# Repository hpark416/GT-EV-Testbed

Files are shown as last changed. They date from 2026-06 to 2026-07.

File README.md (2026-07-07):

# GT-EV-Testbed

### Georgia Tech ME 8803 – Special Problems (EV & Grid)

A custom dual-motor electric vehicle control system built around repurposed Segway/Ninebot hoverboard motors, a FLIPSKY FT85BD dual ESC, and Arduino-based vehicle control.

This project serves as both a proof-of-concept EV platform and an educational testbed for motor control, vehicle dynamics, telemetry, battery systems, and embedded software development.

---

## Project Objectives

The goal of this project is to develop a low-cost, modular electric vehicle platform capable of:

- Differential drive control
- Zero-radius turning
- Radio control operation
- Telemetry collection
- Battery and power monitoring
- Expandable software architecture
- Future BLE/mobile dashboard integration
- Educational demonstrations and experimentation

---

## Current Hardware

### Powertrain

- 2x Segway/Ninebot hoverboard hub motors
- FLIPSKY FT85BD dual ESC
- Stock Segway 15S lithium-ion battery pack
- Emergency stop switch
- Power distribution board
- Main power breaker

### Control System

- Arduino Mega 2560
- Radiolink RC receiver
- Radiolink RC transmitter
- PPM control signal to FT85BD

### Planned Electronics

- Arduino UNO R4 WiFi
- UART telemetry interface
- Bluetooth/mobile dashboard
- Data logging
- Battery monitoring

---

## Vehicle Specifications

### Battery

| Parameter | Value |
|---|---:|
| Chemistry | Lithium-Ion |
| Configuration | 15S |
| Nominal Voltage | ~54.8V |
| Approximate Energy | ~236 Wh |

### Motors

| Parameter | Value |
|---|---:|
| Type | Hoverboard hub motor |
| Quantity | 2 |
| Sensor Type | Hall sensors |
| Pole Pairs | 7 |

### Controller

| Parameter | Value |
|---|---:|
| ESC | FLIPSKY FT85BD |
| Configuration | Dual motor |
| Current Control Method | PPM + UART telemetry (Flipsky protocol) |
| Active tuning focus | Duty-cycle mode for low-ERPM crawl |

---

## Current Software Features

- Radiolink RC input
- Interrupt-based RC pulse capture
- PPM output to FT85BD
- Differential drive
- Arcade-style steering
- Zero-radius pivot mode
- Adjustable forward speed limit
- Separately capped reverse speed
- Steering sensitivity tuning
- Input deadband filtering
- Exponential response shaping
- Ramp-rate limiting
- UART telemetry from FT85BD (`UartSpeedController`, optional ERPM drive)

---

## ESC Configuration

Current controller configuration target:

```text
Control Mode: Speed Reverse
Input Type: PPM
Pulse Range: 1000 us - 1500 us - 2000 us
Motor Startup: Hall
Hall Sensors: Enabled
Master ESC ID: 101
Slave ESC ID: 102
```

---

## Repository Structure

```text
/
├── Arduino/
│   ├── SpeedReverseController/
│   ├── CurrentReverseController/
│   ├── UartSpeedController/
│   ├── UartSpeedController_NanoESP32/   (PlatformIO, Arduino Nano ESP32)
│   ├── Diagnostics/
│   │   ├── UartTelemetry_NanoESP32/
│   │   └── UartTelemetryLogger_NanoESP32/   (SD CSV logger)
│   └── Experimental/
├── Configs/
│   ├── FT85BD_Master/
│   ├── FT85BD_Slave/
│   └── Control_Setups/
├── Docs/
│   ├── Logbook/          ← engineering log (dated photo entries)
│   ├── Wiring/
│   ├── Images/
│   ├── Notes/
│   └── TestLogs/
└── README.md
```

---

## UART Setup (FT85BD ↔ Arduino Mega)

The `Arduino/UartSpeedController/` sketch talks to the FT85BD over the VESC UART protocol at **115200 baud**. It polls telemetry from master ESC **101** (direct UART) and slave ESC **102** (CAN forward through the master).

### 1. Hardware wiring

Use **Arduino Mega Serial1** so USB `Serial` remains free for debug output:

```text
Arduino Mega TX1 (D18)  ->  FT85BD COMM RX
Arduino Mega RX1 (D19)  ->  FT85BD COMM TX
Arduino GND             ->  FT85BD COMM GND
```

Important:

- **Common ground** is required between the Mega and FT85BD.
- FT85BD UART is **3.3 V logic**. The Mega TX line is 5 V — use a **bidirectional level shifter** (recommended) or a resistor divider on the Mega TX → FT85BD RX path. Connect Mega RX to FT85BD TX through the level shifter as well.
- Do **not** connect the Mega to a powered ESC UART port until wiring is verified with a multimeter.
- Keep the **e-stop** and main breaker accessible during all UART bring-up tests.

See `Docs/Wiring/README.md` for the full pin map including PPM and RC wiring.

### 2. FT85BD / VESC Tool configuration

1. Connect the FT85BD to a PC via USB and open **VESC Tool** (or the FLIPSKY configuration app).
2. Confirm controller IDs:
   - Master (left): **101**
   - Slave (right): **102**
3. Under **App Settings → General**, set the app to **UART** (or UART + another input only if you understand the priority rules). For UART-only testing, disconnect PPM control wires to avoid conflicting inputs.
4. Under **App Settings → UART**, confirm baud rate **115200** (default).
5. Under motor settings, confirm **Speed** control mode matches your intent (Speed Reverse for this sketch).
6. Load and write the known-good XML configs from `Configs/FT85BD_Master/`, `Configs/FT85BD_Slave/`, and `Configs/Control_Setups/` as needed.
7. Power-cycle the ESC after writing configuration.

### 3. Upload firmware

**Arduino Mega (Arduino IDE):** open `Arduino/UartSpeedController/UartSpeedController.ino`.

**Arduino Nano ESP32 (PlatformIO):** open `Arduino/UartSpeedController_NanoESP32/` and run `pio run -t upload` (see that folder's `README.md`). Uses D8/D9 for FT85BD UART; 3.3 V logic — no level shifter needed.

For either board:

1. Leave `ENABLE_UART_RPM_CONTROL` set to **`false`** for the first test (telemetry only).
2. Upload the sketch.

### 4. Verify telemetry

1. Open the Serial Monitor at **115200 baud**.
2. With the ESC powered (wheels off the ground), you should see:
   - `FW version: x.xx` after startup (if the master responds)
   - Periodic lines: `ERPM`, `V` (input voltage), `I` (motor current), `Fault`, `ID`
3. Spin a motor by hand or apply a light command — ERPM and current should change.
4. Confirm both IDs **101** and **102** appear as telemetry alternates between master and slave.

If there is no response:

- Swap TX/RX if needed (they must cross).
- Recheck ground and level shifting.
- Confirm only one device drives the UART lines.
- Verify baud rate and that the UART app is enabled on the ESC.

### 5. Enable RC + ERPM control (optional)

Only after telemetry is stable:

1. Set `ENABLE_UART_RPM_CONTROL` to **`true`** and re-upload.
2. Confirm RC receiver wiring (CH2 → D2, CH4 → D3) matches `SpeedReverseController`.
3. Test with wheels **off the ground** and low ERPM limits (`MAX_FORWARD_ERPM`, `MAX_REVERSE_ERPM` in the sketch).
4. Tune `INVERT_MASTER` / `INVERT_SLAVE` so both wheels turn in the expected direction.
5. Verify RC failsafe: releasing signal should command **0 ERPM** on both motors.

### 6. Coexistence with PPM control

`SpeedReverseController` (PPM on D9/D10) and `UartSpeedController` (Serial1) can share the same RC input pins but should **not** drive the ESC simultaneously. Use one control method at a time:

| Mode | ESC input | Arduino sketch |
|---|---|---|
| PPM drive | PPM pins | `SpeedReverseController` |
| UART telemetry / drive | COMM UART | `UartSpeedController` |

---

## Progress Notes

### 2026-06 — UART bring-up (Nano ESP32)

- Verified FT85BD speaks **Flipsky UART** (`AA … DD`), not VESC packets.
- Dual-UART wiring (Serial1 → master 101, Serial2 → slave 102) confirmed for telemetry.
- Diagnostics: `UartTelemetry_NanoESP32` for serial bring-up.

### 2026-07-07 — Control mode evaluation (duty cycle vs speed vs current)

Evaluated FT85BD control modes for differential drive with a human rider on the cart:

| Mode | Result |
|---|---|
| **Current** | Strong torque at low speed, but **too unstable** for differential drive — especially with a rider. Not suitable as the primary cart mode. |
| **Speed** | Good **differential stability**, but at low ERPM (~400 range) motors often **stuck, buzzed, and hummed** — poor crawl behavior. |
| **Duty cycle** | **Smooth motion at low ERPM** (~400 range) without the speed-mode lock-up/buzz. Current working direction for low-speed tuning. |

Added `Arduino/Diagnostics/UartTelemetryLogger_NanoESP32/` — Nano ESP32 + **Adafruit microSD SPI breakout** logs dual-UART telemetry (voltage, RPM, duty, current, temps) to CSV for post-run analysis while testing control modes.

### 2026-07-07 — Engineering logbook from photo narration

- Created **`Docs/Logbook/`** — dated entries for **100+ images** in `Docs/Images/`, transcribed from narration video `Docs/Notes/2026-07-07 16-58-03.mp4` (video gitignored).
- See [`Docs/Logbook/INDEX.md`](Docs/Logbook/INDEX.md) for session index (2026-05-22 through 2026-07-07).

---

## TODO

- [ ] **Steering tuning at low RPM** — `SPEED_STEERING_GAIN` in `UartSpeedController_NanoESP32` is too weak at lower speeds; increase low-RPM steering authority without destabilizing the cart.
- [ ] Correlate SD log CSV data with duty-cycle settings in Flipsky ESC Tool (document optimal duty range around ~400 ERPM).
- [ ] Compare logged duty/RPM/current traces across speed vs duty modes for the same RC input profile.
- [ ] Update FT85BD XML configs in `Configs/` when duty-cycle setup is finalized.
- [ ] Closed-loop wheel sync / telemetry dashboard (BLE or post-processing pipeline from SD logs).

---

## Development Status

### Completed

- Battery integration
- FT85BD bring-up
- Hall sensor motor identification
- RC receiver integration
- Arduino PPM controller
- Differential drive control
- Pivot steering mode
- Initial ESC configuration workflow
- UART telemetry sketch (`UartTelemetry_NanoESP32`, Flipsky protocol)
- Nano ESP32 dual-UART speed controller (`UartSpeedController_NanoESP32`)
- UART telemetry SD logger (`UartTelemetryLogger_NanoESP32`)

### In Progress

- **Duty-cycle control** tuning for smooth low-ERPM crawl (~400 ERPM)
- **Steering gain** at low RPM (`UartSpeedController_NanoESP32`)
- Low-speed control tuning and SD log analysis
- Differential steering refinement
- Configuration management for master/slave ESC settings

### Planned

- ESC config snapshots for duty-cycle mode in `Configs/`
- BLE / mobile telemetry dashboard
- Automated log analysis scripts for SD CSV files
- Closed-loop wheel speed matching

---

## Lessons Learned

- Hoverboard motors are capable low-cost EV drive units.
- Hall sensor startup significantly improves low-speed performance.
- **Current mode** gives torque at crawl speeds but is **unstable for differential drive with a rider** — not viable as the primary cart mode.
- **Speed mode** gives good differential stability but can **buzz/hum and hang at low ERPM** (~400 range).
- **Duty-cycle mode** currently provides the **smoothest low-ERPM motion** on this platform; use SD logging to tune further.
- Flipsky UART (`AA … DD`) is required for FT85BD — not VESC packets.
- PPM remains a proven fallback; UART dual-port telemetry + SD logging supports mode comparison.
- Master/slave ESC IDs and XML configuration files must be carefully version-controlled.

---

## Author

Hyungjun Park  
Georgia Institute of Technology  
ME 8803 – Special Problems (EV & Grid)

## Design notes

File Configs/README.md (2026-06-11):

# FT85BD Configuration Files

This folder stores **FLIPSKY FT85BD XML motor and control setup files** exported from the VESC Tool–compatible configuration workflow.

## Layout

| Folder | Contents |
|---|---|
| `FT85BD_Master/` | Master (left) motor setup XML |
| `FT85BD_Slave/` | Slave (right) motor setup XML |
| `Control_Setups/` | Shared control/input setup XML (PPM mode, calibration, ramp, reverse timing) |

The FT85BD dual ESC uses separate master/slave identities. Do not overwrite one side with the other.

## Controller IDs

Each ESC must have a **unique CAN/controller ID**. Do not duplicate IDs across master and slave.

| ESC | ID |
|-----|----|
| Master | **101** |
| Slave | **102** |

Always verify the connected ESC ID before writing setup.

## Suggested naming convention

```text
Master_MotorSetup_YYYYMMDD.xml
Slave_MotorSetup_YYYYMMDD.xml
Master_ControlSetup_YYYYMMDD.xml
Slave_ControlSetup_YYYYMMDD.xml
```

## File types

- **Motor setup** — motor identification values, current limits, power limits, ERPM limits, and battery settings.
- **Control setup** — input type, PPM mode, PPM calibration, deadband, ramp times, reverse timing, and ESC ID.

## Usage

1. Identify motors and complete hall-sensor detection on each ESC individually.
2. Export XML from the configured unit into the appropriate folder here.
3. Always save the working configuration before experimenting.
4. Commit configs when they represent a known-good, tested setup.
5. Document significant changes in `Docs/Notes/` and `Docs/TestLogs/`.

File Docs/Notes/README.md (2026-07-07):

# Development Notes

Informal scratch notes and **local-only media** (videos are gitignored).

## Engineering logbook

Structured, dated entries with photos are in **[`../Logbook/`](../Logbook/)** — start at [`../Logbook/README.md`](../Logbook/README.md) and [`../Logbook/INDEX.md`](../Logbook/INDEX.md).

Narration source video (local, not in git): `2026-07-07 16-58-03.mp4` in this folder.

## Suggested files

```text
motor_identification.md
battery_observations.md
control_mode_comparison.md
low_speed_tuning.md
speed_reverse_tuning.md
uart_notes.md
```

---

## Test Logs

See also `Docs/TestLogs/` for structured bench and cart test records.

| Date | Sketch / Config | Summary | Result |
|---|---|---|---|
| | | | |

---

## Tuning Notes

- Speed reverse tuning:
- Current reverse tuning:
- Pivot mode parameters:
- RC expo / scaling:

---

## Motor Identification Results

| Motor | Pole Pairs | R (mΩ) | L (µH) | Direction | Notes |
|---|---|---|---|---|---|
| Master (left) | | | | | |
| Slave (right) | | | | | |

---

## Battery Observations

- Resting voltage:
- Under-load behavior:
- Charging / storage notes:

---

## Control Mode Comparisons

| Aspect | Speed Reverse | Current Reverse |
|---|---|---|
| Low-speed feel | | |
| Wheel sync | | |
| Steering response | | |
| Heat / efficiency | | |
| Overall preference | | |

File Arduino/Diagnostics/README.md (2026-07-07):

# Diagnostics

This folder contains sketches used to isolate and verify hardware behavior.

Recommended diagnostic order:

1. RC input pulse reader
2. PPM pass-through
3. Identical PPM output to both ESCs
4. Fixed pulse step test
5. One-motor ESC test
6. UART telemetry test — `UartTelemetry_NanoESP32/` (Nano ESP32, read-only — run this first)
7. UART telemetry SD logger — `UartTelemetryLogger_NanoESP32/` (dual UART + Adafruit microSD CSV log)
8. Full UART controller — `../UartSpeedController_NanoESP32/` (Flipsky protocol, dual UART, drive)

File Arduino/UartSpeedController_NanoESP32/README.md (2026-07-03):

# UartSpeedController — Arduino Nano ESP32 (PlatformIO)

UART speed controller for the **FLIPSKY FT85BD** on the **GT-EV meka cart**, using the **Flipsky FT ESC UART protocol** (`AA … DD`). Replaces PPM with signed **current** commands (cmd 4) over dual COMM ports.

**Firmware version:** `1.1.0` (printed at boot on USB serial).

**Not** VESC packets — uses `../UartSpeedController/FlipskyUart.h`.

## What this program does

The Nano ESP32 sits between the RC receiver and two FT85BD halves (master **101**, slave **102**):

1. **Reads RC PWM** on D2 (throttle) and D3 (steering) via `pulseInLong` polling (reliable on ESP32-S3).
2. **Mixes steering** for a two-motor cart: at speed, slows the inside wheel only (does not boost the outside wheel — reduces spin-out).
3. **Sends UART cmd 4** (`SET_CURRENT`) with signed target current to each ESC every control loop (ESC mode: **Current Bidirectional**).
4. **Brakes at neutral** — when both sticks are centered, commands `0` A to both wheels.
5. **Polls telemetry** (voltage, RPM, current, fault) once per second on USB serial.
6. **Sends keepalive** (cmd 25) once per second to each ESC.

### Drive behavior (current firmware)

| Stick | Behavior |
|---|---|
| Forward | Both wheels drive forward (subject to steering mix) |
| Back | Both wheels reverse (capped lower than forward) |
| Neutral (throttle + steering centered) | **Brake** — `setCurrent(0)` on both ESCs |
| Steering while moving | Inside wheel slows; outside wheel keeps throttle |
| Steering at zero throttle | **No pivot** by default (`ENABLE_PIVOT_STEERING = false`) — pivot was disabled because it caused flip risk on the cart |
| RC signal lost | Immediate stop (`0` A) |

### Why UART instead of PPM

- Finer control (signed current commands, not ~400 µs PPM range).
- No minimum-drive “breakaway kick” that made low-speed PPM choppy.
- Software ramps and expo shape low-speed response smoothly.
- Neutral can command active zero-speed hold instead of ESC center-coast.

## Bring-up summary (from diagnostics)

| Topic | Setting |
|---|---|
| Protocol | Flipsky UART (`AA` + len + payload + CRC16 + `DD`) |
| Baud | **115200** per half, written in Flipsky ESC Tool, power-cycle |
| Input type | **UART** (not PPM) on each ESC half |
| IDs | Master **101**, slave **102** |
| Preferred wiring | **Dual UART** — separate COMM harness per half (verified) |
| Logic level | Nano ESP32 **3.3 V** — direct UART to FT85BD typical |

## Wiring (dual UART — default)

Cross TX/RX on each harness. One common GND.

| Nano ESP32 | Master COMM (101) | Slave COMM (102) |
|---|---|---|
| D9 (TX) | → RX | — |
| D8 (RX) | ← TX | — |
| D5 (TX) | — | → RX |
| D4 (RX) | — | ← TX |
| D2 | RC throttle (CH2) | |
| D3 | RC steering (CH4) | |
| GND | GND | GND |

### Single-harness mode (`CAN_FORWARD_VIA_MASTER`)

Only D8/D9 to master COMM. Telemetry alternates local master + slave via cmd **16**. RPM control on slave uses CAN-forwarded cmd **39** — **dual UART is recommended for drive**.

## Flipsky ESC Tool — Control Setup

Configure **each ESC separately** (connect to master, set ID **101**, write; then slave, ID **102**, write). Battery on. Power-cycle after writing.

### Required settings

| Setting | Master (101) | Slave (102) | Notes |
|---|---|---|---|
| **Input Signal Type** | UART | UART | Must match firmware |
| **Control Mode** | **Current Bidirectional** | **Current Bidirectional** | Firmware sends cmd **4** (`SET_CURRENT`), not cmd 39 |
| **ESC ID** | **101** | **102** | Must match harness / firmware |
| **Baud rate** | 115200 | 115200 | Set on connection screen |

**Do not use** `Current Gear Reverse Brake` or other gear/throttle modes for this project — those expect pedal-like input patterns. This firmware already sends explicit RPM targets.

### Recommended settings (stability)

| Setting | Suggested | Why |
|---|---|-----|
| **Throttle Response Level** | level 1 or 2 | Gentler ESC response; firmware already ramps |
| **Signal Ramp Time Pos / Neg** | 0.20 – 0.30 s | Light ESC-side smoothing; avoid stacking with very slow ramps |
| **Reverse Delay Time** | **0** (or minimal) | Firmware handles forward/reverse instantly |
| **Assisted Turnaround Mode** | **None** | Firmware handles steering; pivot disabled for flip safety |
| **Brake-Parking Mode** | OFF to start | Try ON only if neutral still coasts after `setSpeed(0)` |
| **Slow-Release Motor** | **OFF** | Prevents creeping/coasting at zero command |
| **Minimal Current at Zero Pedal** | defaults / low | Avoid holding motor current when command is zero |
| **Multi-ESC Sync Control** | **OFF** | Each half has its own UART; Nano mixes left/right |
| **Traction Control System** | OFF to start | Optional later — see tuning guide |

### Assisted Turnaround ESC ID Setup

Leave at defaults or ignore — not used. This cart uses **two** ESCs (101/102) on separate UART ports, not the four-corner assisted-turnaround layout.

### Motor direction (both ESCs)

Set rotation direction in **Flipsky ESC Tool → Motor Setup** on each half so that **positive RPM drives the wheel forward** on the cart. Keep `INVERT_MASTER` and `INVERT_SLAVE` **false** in firmware — then straight throttle shows matching signs, e.g. `MasterRPM:22000 SlaveRPM:22000`.

Only use firmware inversion if you cannot change direction in the tool.

### After writing settings

1. **Motor Setup** — invert motor direction on whichever half spins backward when given positive RPM (wheels-up test).
2. Power-cycle both ESCs.
3. Re-flash this firmware if needed.
4. Boot serial should show RC PWM probe + harness check with correct IDs and voltage.

## Prerequisites

- [PlatformIO](https://platformio.org/) (VS Code / Cursor extension or CLI)
- Flipsky ESC Tool V1.6 (or compatible)
- RC receiver outputting **PWM** (not PPM/SBUS) on the wired channels

## Build and upload

```powershell
cd Arduino/UartSpeedController_NanoESP32
pio run -t upload
pio device monitor
```

Windows if `pio` not on PATH:

```powershell
& "$env:USERPROFILE\.platformio\penv\Scripts\pio.exe" run -t upload
& "$env:USERPROFILE\.platformio\penv\Scripts\pio.exe" device monitor
```

Monitor at **115200** baud. Boot prints firmware version first:

```text
Firmware v1.1.0
=== GT-EV-Testbed UartSpeedController (Nano ESP32) ===
Drive: UART cmd 4 SET_CURRENT (ESC: Current Bidirectional)
```

Telemetry prints once per second:

```text
RC  Thr:1520us OK  Str:1500us OK  pwm Thr:412 Str:411
[Master 101]  Vbat:56.57V  RPM:0  I:0.00A  Fault:0  ID:101
[Slave 102]  Vbat:56.67V  RPM:0  I:0.00A  Fault:0  ID:102
Cmd Master:12.5A Slave:12.5A
```

## Firmware configuration (`src/main.cpp`)

### Feature flags

| Constant | Default | Purpose |
|---|---|---|
| `ENABLE_UART_RPM_CONTROL` | `true` | `false` = telemetry only; `true` = RC drives motors |
| `READ_MODE` | `DUAL_UART_PORTS` | Dual COMM vs single UART + CAN forward |

### Speed / current limits

| Constant | Default | Purpose |
|---|---|---|
| `MAX_FORWARD_CURRENT_A` | `40.0` | Forward current cap (amps) |
| `MAX_REVERSE_CURRENT_A` | `15.0` | Reverse current cap (amps) |

### Direction / inversion

| Constant | Default | Purpose |
|---|---|---|
| `INVERT_THROTTLE` | `false` | `true` if forward stick commands reverse |
| `INVERT_STEERING` | `false` | Flip if steering is mirrored |
| `INVERT_MASTER` | `false` | Last resort — prefer motor direction in ESC Tool |
| `INVERT_SLAVE` | `false` | Last resort — prefer motor direction in ESC Tool |

### Throttle feel

| Constant | Default | Purpose |
|---|---|---|
| `THROTTLE_EXPO` | `0.60` | Higher = softer low speed (0.45 aggressive, 0.70 very gentle) |
| `THROTTLE_RAMP_STEP` | `0.015` | Accel smoothing per loop (~5 ms) |
| `THROTTLE_BRAKE_RAMP_STEP` | `0.06` | Faster decel when backing off throttle |
| `RC_DEADBAND_US` | `60` | Stick center deadband (µs) |
| `CMD_ZERO_THRESHOLD` | `0.03` | Normalized threshold for neutral brake |

### Steering / stability

| Constant | Default | Purpose |
|---|---|---|
| `SPEED_STEERING_GAIN` | `0.30` | Turn strength at speed (lower = less spin risk) |
| `MAX_TURN_REDUCTION` | `0.75` | Max inside-wheel slowdown (fraction of throttle) |
| `STEERING_EXPO` | `0.50` | Steering curve shaping |
| `STEERING_RAMP_STEP` | `0.020` | Steering input smoothing |
| `ENABLE_PIVOT_STEERING` | `false` | In-place pivot when throttle near zero — **flip risk** |
| `PIVOT_STEERING_GAIN` | `0.18` | Only if pivot enabled — keep low |

### Timing / telemetry

| Constant | Default | Purpose |
|---|---|---|
| `TELEMETRY_INTERVAL_MS` | `1000` | USB serial report rate |
| `ALIVE_INTERVAL_MS` | `1000` | ESC keepalive (cmd 25) |
| `SIGNAL_TIMEOUT_MS` | `100` | RC lost → stop if no PWM update |

## Tuning guide

### Test order

1. **ESC Tool** — UART, Current Bidirectional, IDs 101/102, power-cycle.
2. **Telemetry only** — `ENABLE_UART_RPM_CONTROL = false`, confirm voltage + IDs on boot.
3. **Wheels up** — enable RPM control, verify forward / reverse / neutral brake.
4. **Wheels down, low limits** — keep `MAX_FORWARD_RPM` at 22000 or lower.
5. **Increase speed** — bump forward cap in steps (e.g. 22000 → 28000 → 35000) only when stable.

### If forward / reverse is wrong

- Stick reversed → toggle `INVERT_THROTTLE`.
- One wheel wrong direction → fix in **ESC Tool Motor Setup** first; only then toggle `INVERT_MASTER` / `INVERT_SLAVE`.

### If low speed is still jerky

- Raise `THROTTLE_EXPO` (try 0.65 – 0.70).
- Lower `THROTTLE_RAMP_STEP` (try 0.010).
- In ESC Tool, lower **Throttle Response Level** or reduce **Signal Ramp** slightly.
- Confirm **Slow-Release Motor** is OFF.

### If it spins out or feels tippy

- Lower `SPEED_STEERING_GAIN` (try 0.20 – 0.25).
- Lower `MAX_FORWARD_RPM`.
- Keep `ENABLE_PIVOT_STEERING = false`.
- Optionally enable **Traction Control** in ESC Tool with conservative `TC Erpm Diff` values.

### If neutral coasts instead of braking

- Firmware already sends `setSpeed(0)` — confirm sticks are truly centered (watch `RC` line in serial).
- In ESC Tool try **Brake-Parking Mode ON**.
- Increase **Brake Light Level** / brake current if the tool exposes it on your firmware version.

### If RC shows STALE / never

- Receiver must output **PWM** (~1000–2000 µs, ~50 Hz), not PPM/SBUS.
- Common GND between Nano and receiver.
- Boot **RC PWM probe** should show `10/10 PWM frames` per channel — move sticks during boot.
- Try swapping a signal wire to confirm receiver channel mapping (CH2 throttle, CH4 steering).

## Bring-up order

1. Flash and run `../Diagnostics/UartTelemetry_NanoESP32/` first — confirm voltage + IDs.
2. Configure both ESCs in Flipsky ESC Tool (see above).
3. Flash this project with `ENABLE_UART_RPM_CONTROL = false` — boot harness check should match.
4. Wheels off ground → `ENABLE_UART_RPM_CONTROL = true` → test direction and neutral brake.
5. Low-speed ground test → tune per guide → raise RPM caps gradually.

## Troubleshooting

| Issue | Fix |
|---|-----|
| `Unknown board ID 'arduino_nano_esp32'` | Use espressif32 `develop` platform — see `platformio.ini` |
| `NO REPLY` on harness check | Swap RX/TX for that port; battery on; UART input in tool |
| Wrong ID on harness | Master/slave harness swapped; fix ESC ID in tool |
| No motor response with RPM enabled | Input Signal Type = UART; Control Mode = Current Bidirectional |
| Motor runs wrong direction | `INVERT_THROTTLE` / `INVERT_MASTER` / `INVERT_SLAVE` |
| RC STALE / never | PWM wiring, GND, channel mapping — see tuning guide |
| Stale VESC-based build | Rebuild — this project uses `FlipskyUart.h` only |

## Protocol reference

| Command | ID | Use |
|---|-----|-----|
| Obtain data | 0 | Telemetry (voltage, RPM, current) |
| CAN forward | 16 | Poll slave on single UART |
| FW version | 17 | Boot probe |
| Keepalive | 25 | Sent every 1 s |
| Set speed | 39 | Not used by this firmware (use cmd 4) |
| Set current | 4 | Signed target current (RC drive) |

See `../../ESCtool/Flipsky ESC Tool/.../ftesc_v1.4_1.5_1.6_uart_handle.c` and `../Diagnostics/UartTelemetry_NanoESP32/README.md` for details.

## Development notes

| Date / phase | Work |
|---|---|
| v1.0.x | Dual UART telemetry + cmd 39 RPM drive |
| v1.2.0 | PPM drive on D6/D10 (proven path); optional UART cmd 32 gear+current |
| v1.1.0 | cmd 4 SET_CURRENT for Current Bidirectional ESC mode; firmware version in boot log |
| Initial | Dual UART telemetry + RPM control from `UartTelemetry_NanoESP32` bring-up |
| Telemetry | 1 Hz USB report; RC throttle/steering in each line |
| RC input | ESP32-S3: switched from ISR to `pulseInLong` polling; boot PWM probe |
| Drive tuning | Meka cart profile: brake-at-neutral, slow-inside steering, pivot off, lower RPM caps, throttle expo/ramps |

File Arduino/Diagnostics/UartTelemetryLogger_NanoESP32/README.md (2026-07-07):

# UART Telemetry SD Logger — Arduino Nano ESP32

Records **read-only** FT85BD telemetry from both ESC halves to a **CSV file** on an **Adafruit microSD SPI breakout**. Intended for bench and cart test sessions while comparing ESC control modes (duty cycle, speed, current).

Based on the dual-UART layout from `UartTelemetry_NanoESP32` and `UartSpeedController_NanoESP32`. Sends **no** motor commands.

## Why this exists

Use this logger to capture voltage, RPM, duty cycle, current, and temperature while evaluating low-speed drive behavior — especially after switching to **duty-cycle control** (~400 ERPM) where speed mode tended to buzz/hum and current mode was unstable for differential drive with a rider.

## Wiring

### FT85BD UART (dual — same as speed controller)

| Nano ESP32 | Master COMM (101) | Slave COMM (102) |
|---|---|---|
| D9 (TX) | → RX | — |
| D8 (RX) | ← TX | — |
| D5 (TX) | — | → RX |
| D4 (RX) | — | ← TX |
| GND | GND | GND |

### Adafruit microSD SPI breakout

| Breakout | Nano ESP32 |
|---|---|
| 3V3 | 3V3 |
| GND | GND |
| CLK | D13 (SCK) |
| DO (MISO) | D12 |
| DI (MOSI) | D11 |
| CS | D7 |

Use a **FAT32** microSD card (≤32 GB recommended). Format on a PC if the card is blank.

## ESC prerequisites

1. Flipsky ESC Tool: **UART** input @ **115200** on each half (written to flash, power-cycle).
2. Master ID **101**, slave ID **102**.
3. Battery on for COMM replies.

## Build and upload

```bash
cd Arduino/Diagnostics/UartTelemetryLogger_NanoESP32
pio run -t upload
pio device monitor
```

## Output

Each boot creates the next free file: `/tel_001.csv`, `/tel_002.csv`, …

CSV columns:

```text
millis_ms,esc_id,vbat_v,rpm,motor_a,input_a,duty,fet_c,motor_c,fault
```

Header comment lines (`#`) record session metadata. Files flush every 32 rows and every 3 s.

Serial monitor prints a short live view plus `rows=` / RX byte counts every 5 s.

## Typical workflow

1. Confirm basic UART with `../UartTelemetry_NanoESP32/`.
2. Set ESC control mode in Flipsky tool (e.g. duty cycle).
3. Flash this logger, run the test maneuver, power off.
4. Remove SD card and analyze CSV in Excel / Python / `Docs/TestLogs/`.

## Troubleshooting

| Symptom | Check |
|---|---|
| `SD init FAILED` | CS=D7, SPI wiring, FAT32 card, 3V3 to breakout |
| No UART rows | Same as `UartTelemetry_NanoESP32` — battery, TX/RX swap |
| `duty` always 0 | ESC may not report duty in telemetry for all modes; RPM/current still valid |
| Empty file after run | Wait for flush (power off after status line) or call longer test |

## Related

- `../UartTelemetry_NanoESP32/` — serial-only bring-up
- `../../UartSpeedController_NanoESP32/` — vehicle controller (PPM / UART drive)

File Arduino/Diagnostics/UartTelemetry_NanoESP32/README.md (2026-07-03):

# UART Telemetry Diagnostic — Arduino Nano ESP32

Minimal **read-only** bring-up test for the **Flipsky FT85BD** dual ESC over COMM UART.

- Uses **Flipsky FT ESC UART** (`AA … DD` frames, Modbus CRC16) via `../../UartSpeedController/FlipskyUart.h`
- **Not** VESC packets (`0x02 … 0x03`) — older `VescUart.h` does not work on FT85BD
- No RC input. No motor commands (`SET_RPM` is never sent)

## Bring-up findings (verified on hardware)

| Topic | Finding |
|---|---|
| Protocol | FT85BD speaks **Flipsky UART**, not VESC. Telemetry cmd **0**, FW cmd **17**, alive cmd **25**. |
| Baud | **115200** — must be set in Flipsky ESC Tool per half, written to flash, then power-cycle. |
| Battery | Pack must be on for COMM to respond (USB tool live data also needs battery). |
| Signal type | Input must be **UART** (not PPM) on each half in the tool. |
| Controller IDs | Master **101**, slave **102** — configure **each half separately** in the tool. |
| Dual read | **Dual UART** (separate COMM harness per half) is verified and preferred when both wires exist. |
| CAN forward | Alternate mode: 3 wires to master only, slave polled via UART cmd **16** + target ID — depends on internal CAN between halves. |
| Logic level | Nano ESP32 is **3.3 V**; direct UART to FT85BD COMM is typical. |
| Parasitic power | ESC TX idle-high can dimly power the Nano LED when USB is unplugged — use common GND, avoid back-power surprises. |
| Raw frames | Healthy traffic starts with `AA`; example: `AA 01 19 … DD` (alive), `AA 0C 11 01 06 …` (FW 1.6), telemetry replies follow. |

### Verified dual-UART results

With both harnesses wired and firmware flashed:

- Master on D8/D9: **ID 101**, ~56.7 V pack, FW **1.6**, fault 0 at idle
- Slave on D4/D5: **ID 102**, matching pack voltage, independent RX byte counters
- Boot prints per-port FW probe and one-shot harness check before continuous polling

## Read modes

Set `READ_MODE` at the top of `src/main.cpp`:

| Mode | Wiring | When to use |
|---|---|---|
| `DUAL_UART_PORTS` **(default)** | 6 signal wires + GND — Serial1 → master, Serial2 → slave | Separate COMM harness per half (verified) |
| `CAN_FORWARD_VIA_MASTER` | 3 wires + GND — Serial1 → master only | Single harness; slave via cmd 16 forward |

Poll interval **125 ms** (~8 Hz per ESC in dual mode). Alive ping every **1 s**. RX stats every **2 s**.

## Wiring (dual UART — default)

Cross TX/RX on **each** harness. One common GND is enough.

| Nano ESP32 | Master COMM (ID 101) | Slave COMM (ID 102) |
|---|---|---|
| D9 (TX) | → RX | — |
| D8 (RX) | ← TX | — |
| D5 (TX) | — | → RX |
| D4 (RX) | — | ← TX |
| GND | GND | GND |

### Wiring (CAN-forward mode)

| Nano ESP32 | Master COMM only |
|---|---|
| D9 (TX) | → RX |
| D8 (RX) | ← TX |
| GND | GND |

Wheels off the ground for any accidental spin.

## ESC prerequisites

1. **Flipsky ESC Tool** — connect each half via USB, set input signal **UART**, baud **115200**, write config, power-cycle.
2. Master ID **101** on the master half; slave ID **102** on the slave half.
3. Battery on before expecting UART replies.

## Build and upload

From this directory (Windows — use full `pio` path if not on PATH):

```powershell
& "$env:USERPROFILE\.platformio\penv\Scripts\pio.exe" run -t upload
& "$env:USERPROFILE\.platformio\penv\Scripts\pio.exe" device monitor
```

Linux/macOS:

```bash
pio run -t upload
pio device monitor
```

Serial monitor: **115200 baud**.

Shared header path is set in `platformio.ini`: `-I ../../UartSpeedController`

### PlatformIO / upload notes

| Issue | Fix |
|---|-----|
| `No module named 'intelhex'` | `pip install intelhex` in `%USERPROFILE%\.platformio\penv\Scripts\pip.exe` |
| DFU upload `LIBUSB_ERROR_NOT_FOUND` (2341:0070) | Install **Arduino ESP32 Boards** USB drivers via Arduino IDE 2.x, or set `upload_protocol = esptool` in `platformio.ini` |
| `Unknown board ID 'arduino_nano_esp32'` | Use espressif32 `develop` platform — see comment in `platformio.ini` |

## Expected serial output

Boot (dual UART):

```text
=== FT85BD UART Telemetry Diagnostic ===
Mode: dual UART (master + slave COMM ports)
Wiring (cross TX/RX, common GND):
  Master: D9->COMM RX   D8<-COMM TX
  Slave:  D5->COMM RX   D4<-COMM TX
  GND -> both ESC GND

Master FW: 1.6
Slave FW: 1.6

--- Harness check (one telemetry read each) ---
[Master 101]  Vbat: 56.70 V   RPM: 0   I: 0.00 A   Fault: 0   ID: 101
[Slave 102]   Vbat: 56.68 V   RPM: 0   I: 0.00 A   Fault: 0   ID: 102

Polling both ESCs...
```

Continuous loop:

```text
RX bytes  master=1200  slave=1150
Master raw RX (16): AA 01 19 8A 7E DD AA 0C 11 01 06 ...
Slave raw RX (16): AA 01 19 8A 7E DD ...
[Master 101]  Vbat: 56.69 V   RPM: 0   I: 0.00 A   Fault: 0   ID: 101
[Slave 102]   Vbat: 56.70 V   RPM: 0   I: 0.00 A   Fault: 0   ID: 102
```

## Troubleshooting

| Symptom | Check |
|---|---|
| `NO REPLY (RX bytes=0)` | TX/RX swapped on that harness? GND? Battery on? UART @ 115200 written per half? |
| `Master FW: no reply` / `Slave FW: no reply` | Same as above; try swapping RX/TX for that port only |
| `expected ID 101, got 102` (or vice versa) | Harness plugged into wrong ESC half — swap master/slave wires |
| Only one side in log, old format `[Master COMM]` / single `UART RX bytes:` | Re-flash this project — stale firmware before dual-UART build |
| Raw bytes never start with `AA` | Wrong protocol or baud; confirm Flipsky framing, not VESC |
| Flipsky ESC Tool works over USB but Nano does not | Battery required; confirm UART input type on ESC, not PPM |

## Protocol reference

Flipsky UART framing (implemented in `FlipskyUart.h`):

| Item | Value |
|---|---|
| Frame | `0xAA` + len + payload + CRC16 + `0xDD` |
| CRC | Modbus CRC16 |
| Telemetry | cmd **0** (`FTESC_UART_OBTAIN_DATA_ONCE`) |
| Firmware version | cmd **17** |
| Keepalive | cmd **25** |
| CAN forward | cmd **16** + target CAN ID (single-UART slave poll) |

Source reference in repo tooling: `ESCtool/Flipsky ESC Tool/.../ftesc_v1.4_1.5_1.6_uart_handle.c`

## Next steps

After both halves read voltage and IDs correctly:

1. Flash `../../UartSpeedController_NanoESP32/` with `ENABLE_UART_RPM_CONTROL = false` and confirm boot harness check.
2. Enable RPM control only after telemetry is stable (wheels off ground, low RPM limits).

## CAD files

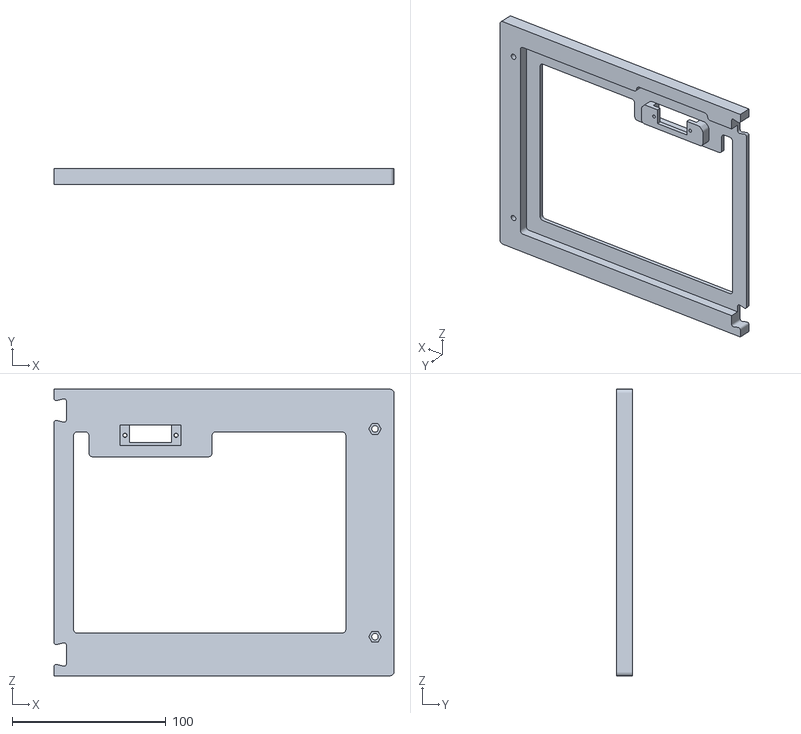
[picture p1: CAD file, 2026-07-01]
PhysicalPrototyping/CadFiles/BatteryDock/3DprintBatDockLargeV1.2.stl
221.0 x 10.1 x 186.3

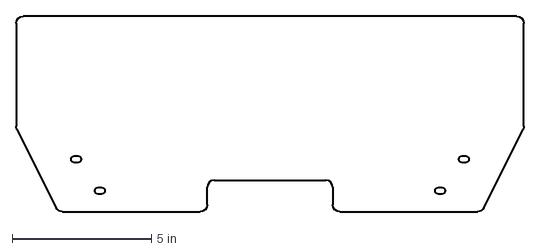
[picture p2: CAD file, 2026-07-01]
PhysicalPrototyping/LaserPanels/RearElectronicsPlate Drawing v1 Sheet1.dxf
18.2 x 7.00 in

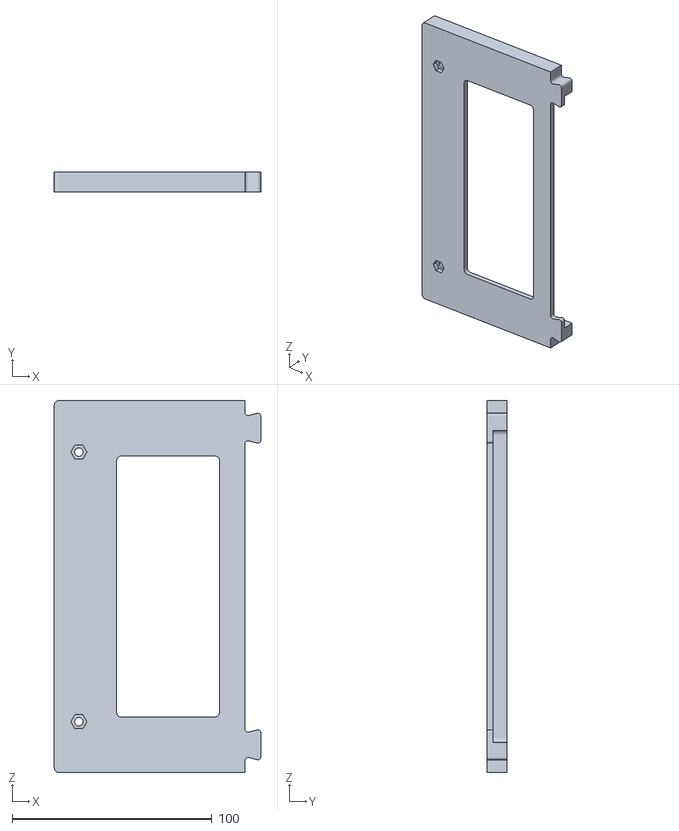
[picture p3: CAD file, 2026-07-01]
PhysicalPrototyping/CadFiles/BatteryDock/3DprintBatDockSmallV1.2.stl
103.5 x 10.1 x 186.3

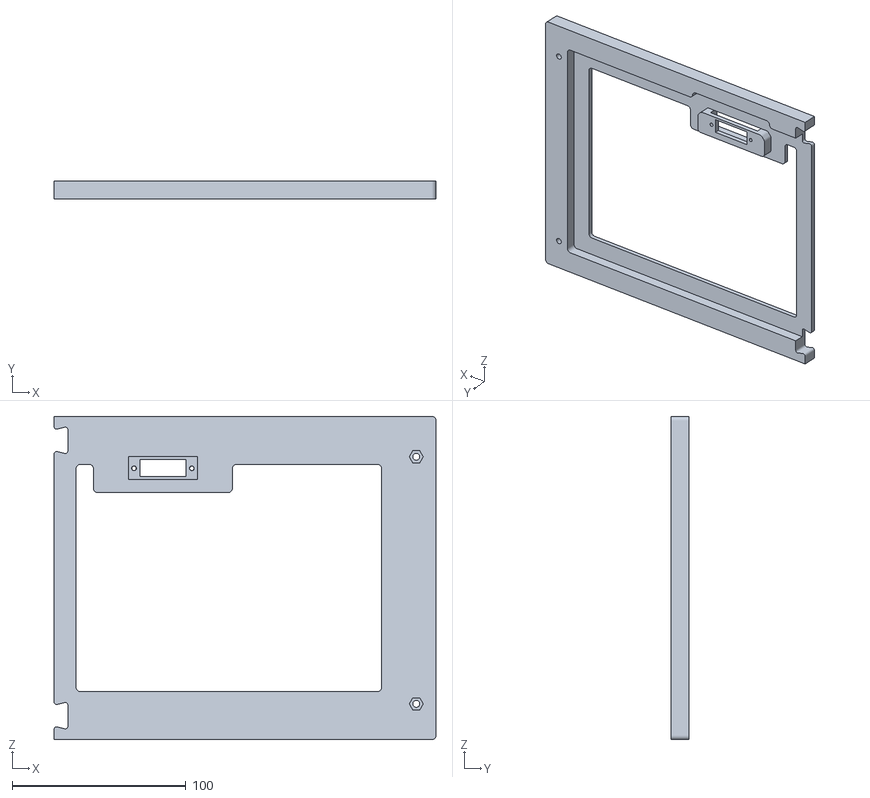
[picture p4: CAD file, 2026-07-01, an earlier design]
PhysicalPrototyping/CadFiles/BatteryDock/3DprintBatDockLargeV1.0.stl
220.0 x 10.1 x 186.3

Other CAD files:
PhysicalPrototyping/CadFiles/BatteryDock/3DprintBatDockSmallV1.0.stl
PhysicalPrototyping/CadFiles/BatteryDock/3DprintBatDockLargeV1.1.stl
PhysicalPrototyping/CadFiles/BatteryDock/3DprintBatDockSmallV1.1.stl

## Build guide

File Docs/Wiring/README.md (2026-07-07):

# Wiring Notes

## Arduino Mega

Current intended wiring:

```text
Radiolink CH2 signal -> Arduino Mega D2
Radiolink CH4 signal -> Arduino Mega D3

Arduino Mega D9  -> FT85BD Master PPM
Arduino Mega D10 -> FT85BD Slave PPM

Arduino Mega TX1 (D18) -> FT85BD COMM RX  (use 3.3 V level shifter)
Arduino Mega RX1 (D19) -> FT85BD COMM TX  (use 3.3 V level shifter)

All grounds common.
```

### Arduino Nano ESP32 (UartSpeedController_NanoESP32)

```text
Radiolink CH2 -> D2
Radiolink CH4 -> D3

Master UART: D9->COMM RX  D8<-COMM TX
Slave UART:  D5->COMM RX  D4<-COMM TX
GND -> both ESC COMM GND

PPM (optional): D6 master, D10 slave
```

### Arduino Nano ESP32 + Adafruit microSD (UartTelemetryLogger_NanoESP32)

Same dual UART as above, plus SPI microSD breakout:

```text
SD CS   -> D7
SD MOSI -> D11
SD MISO -> D12
SD SCK  -> D13
SD 3V3  -> 3V3
SD GND  -> GND
```

Nano ESP32 UART is 3.3 V (direct connection to FT85BD COMM is typical). Built and uploaded via PlatformIO.

## FT85BD UART (COMM port)

```text
Mega TX1 (D18) -> FT85BD COMM RX
Mega RX1 (D19) -> FT85BD COMM TX
GND            -> GND

Baud rate: 115200
Protocol:  Flipsky UART (AA ... DD) — not VESC packets
Master ID: 101
Slave ID:  102
```

Use a bidirectional 3.3 V / 5 V level shifter between the Mega and FT85BD UART pins. Do not tie PPM and UART active control together at the same time — see README UART setup section.

## RC Receiver

Current intended assignment:

```text
CH2 -> throttle
CH4 -> steering
```

Add battery, ESC, E-stop, and power distribution wiring notes here.

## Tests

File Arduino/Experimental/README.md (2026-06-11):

# Experimental Arduino Sketches

This folder is for **unstable or one-off test sketches**. Code here should not be considered stable vehicle firmware.

## Guidelines

- Do **not** flash experimental code to the cart without reviewing safety interlocks (e-stop, power sequencing, and RC failsafe behavior).
- Prefer descriptive filenames or subfolders (e.g. `uart-telemetry-probe/`, `ppm-calibration/`).
- Document what each experiment tests and any hardware prerequisites in a short comment at the top of the source file.

When an experiment matures into a reliable control strategy, promote it to `SpeedReverseController/`, `CurrentReverseController/`, or a new top-level sketch folder.

## Current files

| File | Purpose |
|---|---|
| `Updated_FT85BD_PPM_PivotSteering.cpp` | Pivot steering tuning experiment |
| `Updated_FT85BD_PPM_Breakaway_Assist.cpp` | Low-speed breakaway / startup assist experiment |

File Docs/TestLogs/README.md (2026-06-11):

# Test Logs

Use this folder to record bench and cart tests.

Suggested log format:

```markdown
# YYYY-MM-DD Test Name

## Configuration

- Motor setup:
- Control setup:
- Arduino sketch:
- Battery voltage:
- Test surface:
- Wheels loaded/unloaded:

## Observations

## Issues

## Next changes
```

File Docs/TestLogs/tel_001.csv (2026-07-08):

# GT-EV-Testbed UART telemetry log
# session_start_ms | 4068
# master_id | 101 | slave_id | 102
# poll_ms=125 | dual_uart | read_only
millis_ms | esc_id | vbat_v | rpm | motor_a | input_a | duty | fet_c | motor_c | fault
4410 | 102 | 3.600 | 0 | 0.0000 | 0.0000 | -0.13970 | 26.1 | -60.0 | 8
4416 | 102 | 3.620 | 0 | 0.0000 | 0.0000 | -0.15240 | 26.2 | -60.0 | 8
4537 | 102 | 3.590 | 0 | 0.0000 | 0.0000 | -0.14040 | 26.1 | -60.0 | 8
4537 | 102 | 3.610 | 0 | 0.0000 | 0.0000 | -0.15480 | 26.2 | -60.0 | 8
4662 | 102 | 3.600 | 0 | 0.0000 | 0.0000 | -0.14260 | 26.1 | -60.0 | 8
4662 | 102 | 3.610 | 0 | 0.0000 | 0.0000 | -0.15280 | 26.2 | -60.0 | 8
4787 | 102 | 3.610 | 0 | 0.0000 | 0.0000 | -0.13920 | 26.1 | -60.0 | 8
4787 | 102 | 3.620 | 0 | 0.0000 | 0.0000 | -0.15450 | 26.2 | -60.0 | 8
4912 | 102 | 3.590 | 0 | 0.0000 | 0.0000 | -0.13800 | 26.1 | -60.0 | 8
4914 | 102 | 3.620 | 0 | 0.0000 | 0.0000 | -0.15410 | 26.2 | -60.0 | 8
5037 | 102 | 3.600 | 0 | 0.0000 | 0.0000 | -0.14130 | 26.1 | -60.0 | 8
5037 | 102 | 3.620 | 0 | 0.0000 | 0.0000 | -0.15230 | 26.2 | -60.0 | 8
5162 | 102 | 3.600 | 0 | 0.0000 | 0.0000 | -0.13960 | 26.1 | -60.0 | 8
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

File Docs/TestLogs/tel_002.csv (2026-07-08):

# GT-EV-Testbed UART telemetry log
# session_start_ms | 3995
# master_id | 101 | slave_id | 102
# poll_ms=125 | dual_uart | read_only
millis_ms | esc_id | vbat_v | rpm | motor_a | input_a | duty | fet_c | motor_c | fault
4330 | 102 | 57.770 | 265 | 0.0912 | 0.0001 | 0.03420 | 25.9 | -60.0 | 0
4336 | 102 | 57.860 | 50 | 0.0109 | 0.0000 | 0.01500 | 26.0 | -60.0 | 0
4455 | 102 | 57.760 | 185 | 0.0000 | 0.0000 | 0.03030 | 25.9 | -60.0 | 0
4455 | 102 | 57.840 | 214 | 0.0000 | 0.0000 | 0.01770 | 26.0 | -60.0 | 0
4580 | 102 | 57.780 | 113 | 0.0000 | 0.0000 | 0.03220 | 25.9 | -60.0 | 0
4580 | 102 | 57.860 | 171 | 0.0000 | 0.0000 | 0.02230 | 26.0 | -60.0 | 0
4705 | 102 | 57.790 | 136 | 0.0000 | 0.0000 | 0.03700 | 25.9 | -60.0 | 0
4705 | 102 | 57.860 | 246 | 0.0000 | 0.0000 | 0.00890 | 26.0 | -60.0 | 0
4830 | 102 | 57.760 | 520 | 0.0000 | 0.0000 | -0.03420 | 25.9 | -60.0 | 0
4830 | 102 | 57.860 | 59 | 0.0000 | 0.0000 | 0.01410 | 26.0 | -60.0 | 0
4955 | 102 | 57.760 | 286 | 0.0000 | 0.0000 | 0.03220 | 25.9 | -60.0 | 0
4955 | 102 | 57.860 | 121 | 0.0000 | 0.0000 | 0.01160 | 26.0 | -60.0 | 0
5080 | 102 | 57.750 | 306 | 0.0000 | 0.0000 | 0.02310 | 25.9 | -60.0 | 0
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

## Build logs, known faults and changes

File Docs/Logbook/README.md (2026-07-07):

# GT-EV-Testbed Engineering Logbook

Chronological engineering record for the ME 8803 EV cart (Mecha kit + hoverboard drivetrain + FT85BD dual ESC).

## How this logbook was created

1. Photos were captured during build/test sessions and saved under [`../Images/`](../Images/).
2. Image filenames use **`MMDDYY-N.png`** (e.g. `70726-3` = 2026-07-07, image 3).
3. On **2026-07-07**, a narration video (`Docs/Notes/2026-07-07 16-58-03.mp4`) dictated what each picture shows. That video is **gitignored** (local only).
4. The narration was transcribed to [`_source/2026-07-07_video_transcript.txt`](_source/2026-07-07_video_transcript.txt) and converted into dated entries below.

## Using the logbook

| Resource | Purpose |
|---|---|
| [**INDEX.md**](INDEX.md) | Table of all sessions by date |
| **YYYY-MM-DD.md** | One file per work session with per-image entries |
| [`../TestLogs/`](../TestLogs/) | Structured test-run templates |
| [`../Notes/`](../Notes/) | Informal scratch notes |

## Entry format

Each image entry includes:

- **Image ID** matching the filename in `Docs/Images/`
- Embedded image preview
- **Supporting text** — cleaned engineering description from narration

## Sessions at a glance

See [**INDEX.md**](INDEX.md) for the full list (May 2026 → July 2026):

- Power harness and battery adapter work
- Motor phase / hall harness bring-up
- Mecha kit rear carrier mechanical design
- Battery 3D-print frame iterations
- First integrated rear-panel prototype
- UART telemetry and control-mode evaluation
- Duty-cycle low-speed tuning (July 2026)

## Regenerating entries

If the narration video is re-recorded or captions are corrected, edit `_generate_logbook.py` and run:

```bash
python Docs/Logbook/_generate_logbook.py
```

Or edit individual `YYYY-MM-DD.md` files directly for manual corrections.

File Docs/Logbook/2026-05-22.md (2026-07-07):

# 2026-05-22 — Stock battery connector and power distribution

Makeshift bullet-connector adapter from the stock Segway battery to XT60 anti-spark output; bus bar layout planning.

---

## 52226-1 — Stock battery connector adapter

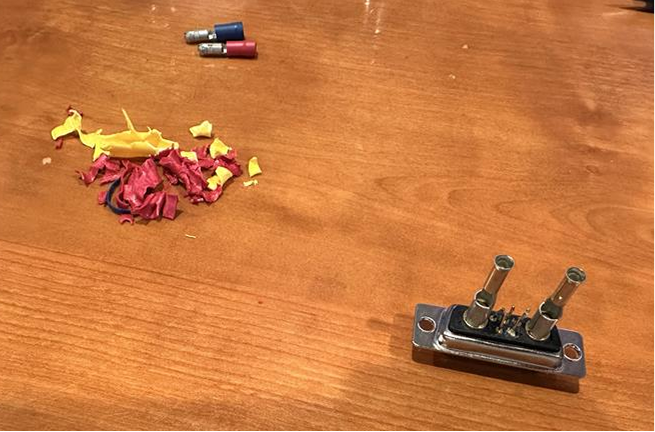
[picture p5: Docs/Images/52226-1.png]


Connector fabricated by de-shelling an existing bullet-type connector and adapting it to a 7W2 gold-plated high-current sub-adapter.

## 52226-2 — Adapter prep for soldering

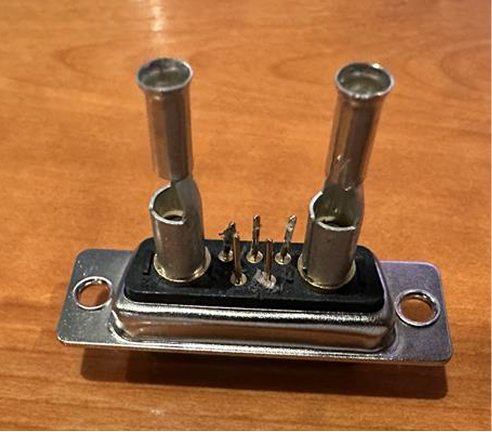
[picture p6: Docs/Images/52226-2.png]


Connector staged for soldering the makeshift adapter to the stock battery connector.

## 52226-3 — Power bus bars

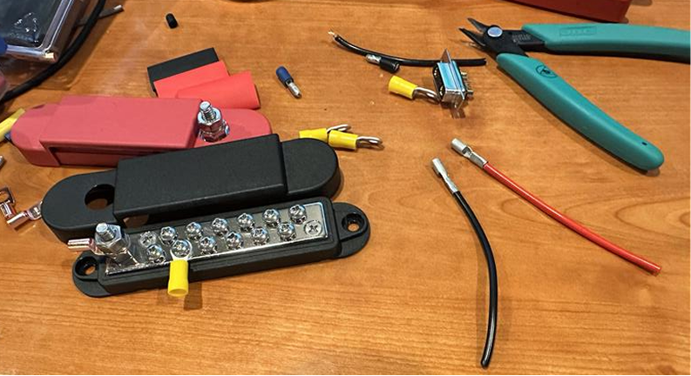
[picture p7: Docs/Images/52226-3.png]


Bus bars that will distribute power from the main battery to subsystems.

## 52226-4 — Bus bar tap detail

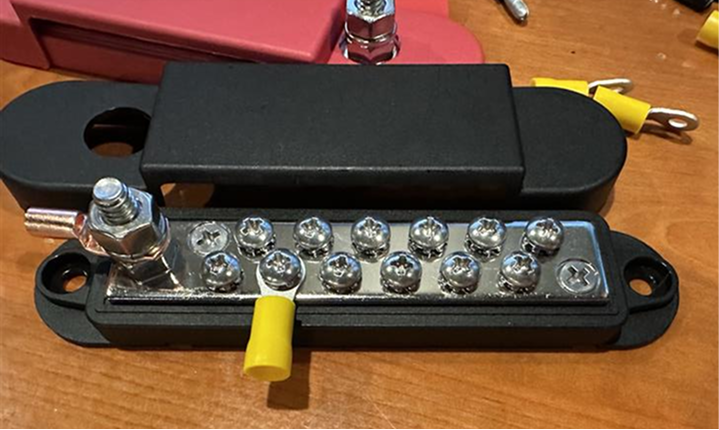
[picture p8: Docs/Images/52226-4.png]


Close-up of a bus bar with a connector tapping power for downstream subsystems.

## 52226-5 — Soldered stock connector

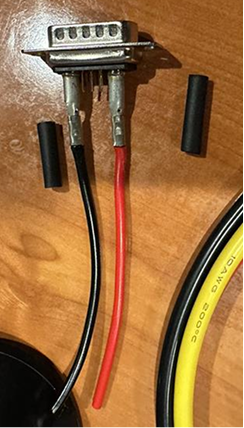
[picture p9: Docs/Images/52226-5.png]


Close-up of the soldered makeshift adapter on the stock connector.

## 52226-6 — Adapter process note

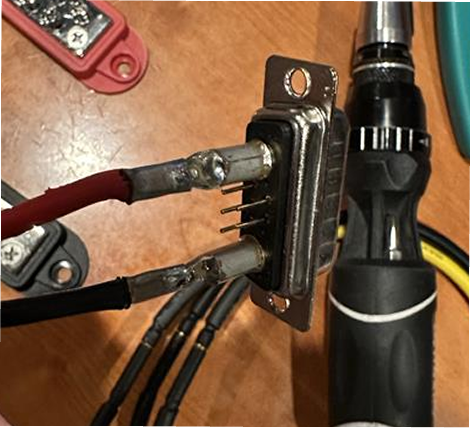
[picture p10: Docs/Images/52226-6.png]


Interim adapter when correct parts were unavailable; documents soldering and heat-shrink insulation steps to follow.

## 52226-7 — Solder fill on adapter

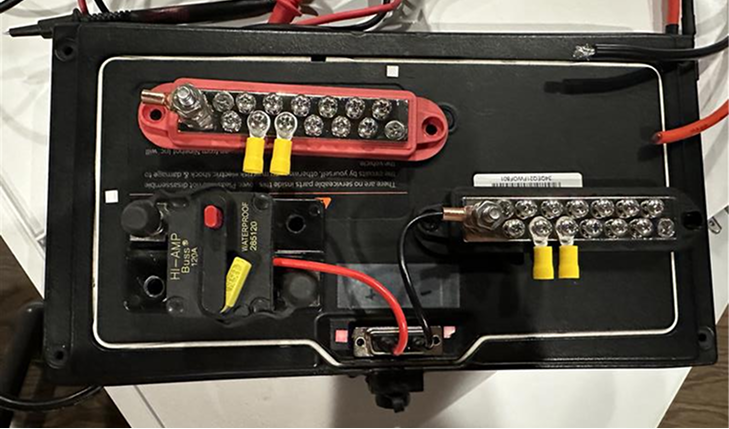
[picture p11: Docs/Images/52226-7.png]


Soldering to lock the makeshift connector to the stock connector.

## 52226-8 — Layout estimate

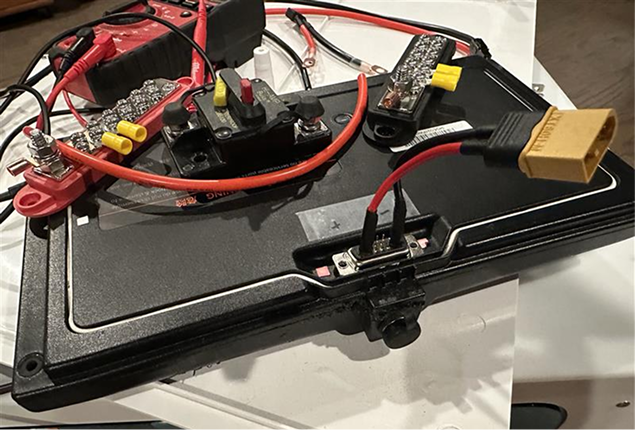
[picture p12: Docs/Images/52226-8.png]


Approximate path: battery adapter → 120 A breaker → distribution (layout not final).

## 52226-9 — XT60 anti-spark output

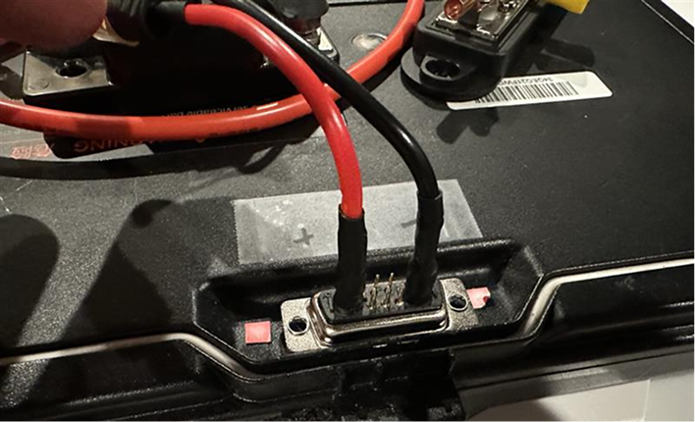
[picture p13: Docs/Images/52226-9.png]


Tap terminates in XT60; battery rear labeled +/−.

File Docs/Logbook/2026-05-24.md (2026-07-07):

# 2026-05-24 — Motor phase harnesses and first ESC power-on

Anderson pole motor leads, crimp quality checks, first dual-ESC power-up, hoverboard hub inspection and hall wiring.

---

## 52426-1 — Connector assortment

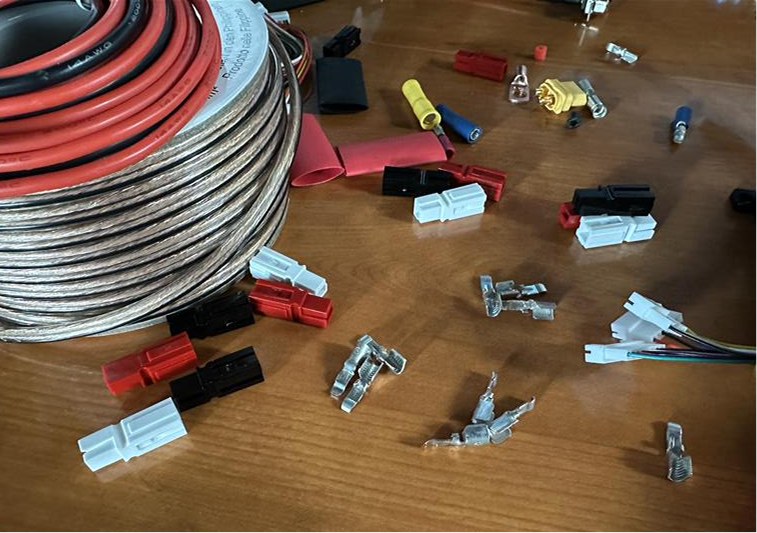
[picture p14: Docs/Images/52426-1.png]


XT60, bus bar lugs, Anderson PP connectors gathered for harness work.

## 52426-2 — Motor lead strip length

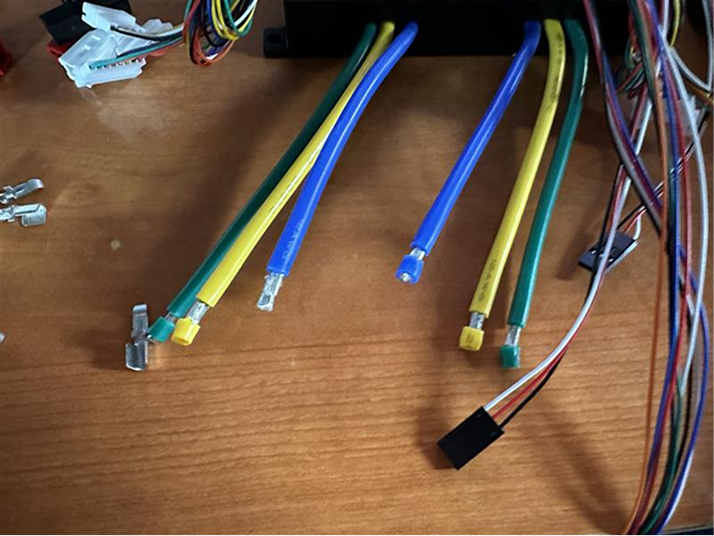
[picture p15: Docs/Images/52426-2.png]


Motor wires stripped ~2 mm before Anderson crimping.

## 52426-3 — Anderson crimp tool

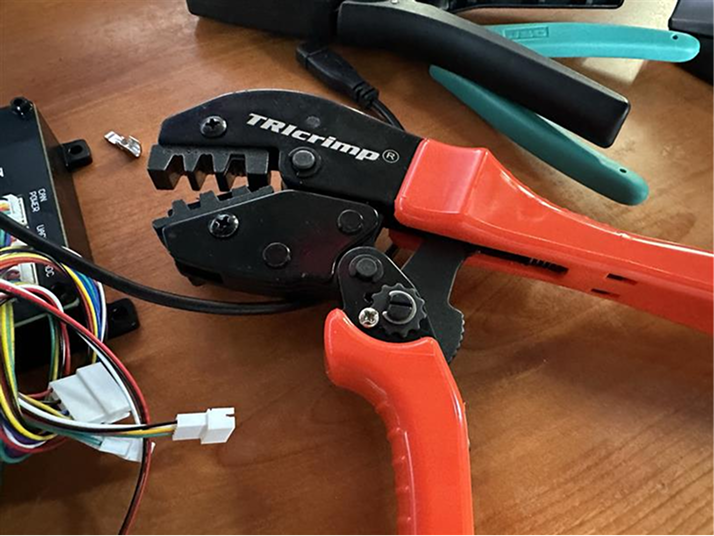
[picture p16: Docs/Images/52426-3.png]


Crimp tool for Anderson pole terminals.

## 52426-4 — Crimped leads with housings

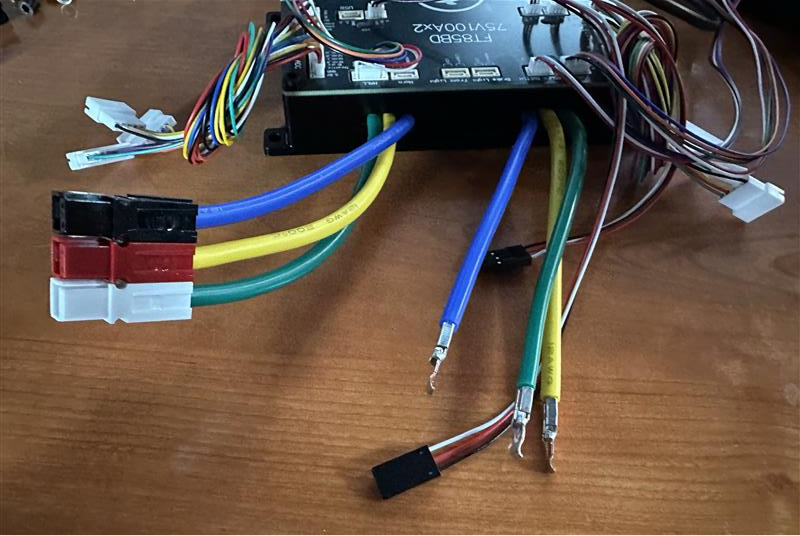
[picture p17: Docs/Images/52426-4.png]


Crimped leads and housed assemblies; keep phase color mapping consistent.

## 52426-5 — Good crimp reference

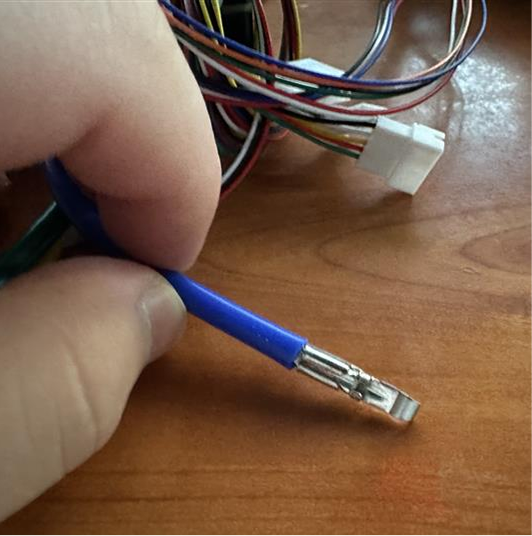
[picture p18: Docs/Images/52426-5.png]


Target crimp quality; verify continuity and low resistance after every crimp.

## 52426-6 — Completed motor harnesses

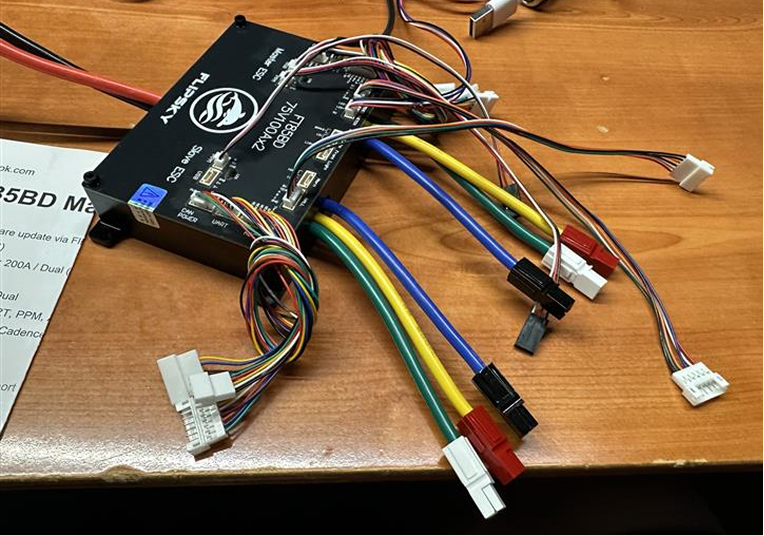
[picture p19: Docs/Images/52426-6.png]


Both motor phase harnesses with Anderson housings.

## 52426-7 — First system power-on

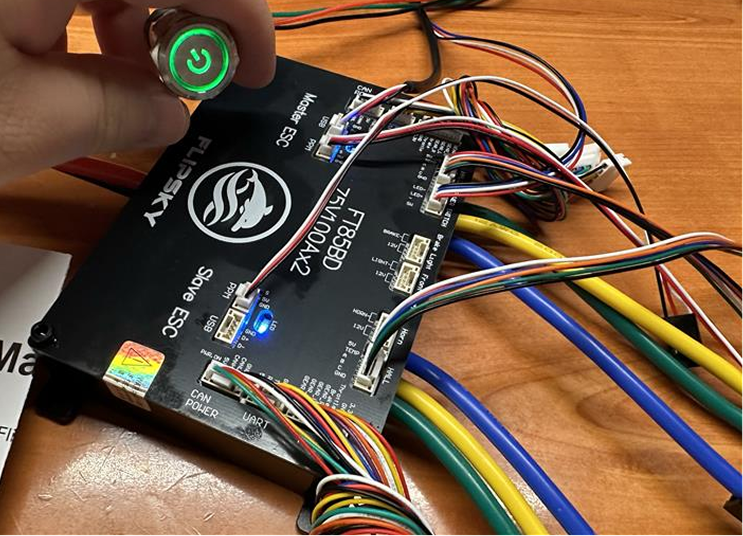
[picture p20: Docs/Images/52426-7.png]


Green alive LED; LED1/LED2 show both motor channels up.

## 52426-8 — Hoverboard hub wheel

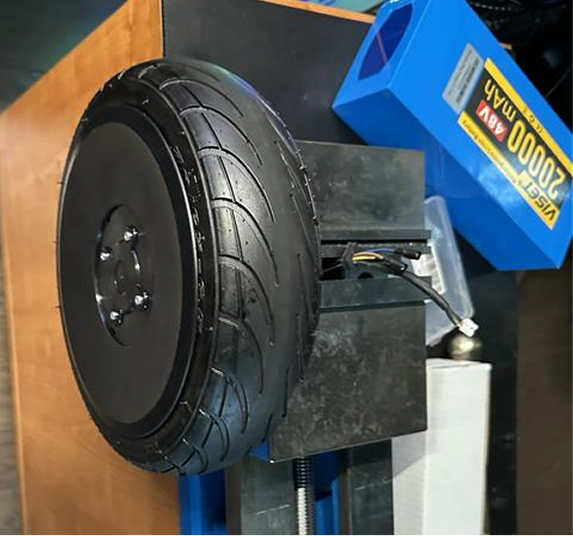
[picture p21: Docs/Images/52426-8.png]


Wheel out of chassis; record diameter and sidewall markings.

## 52426-9 — ESC-to-hub connection

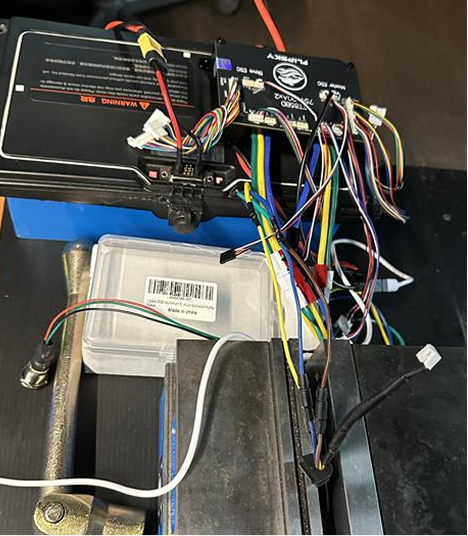
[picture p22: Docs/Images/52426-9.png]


Brown/blue/yellow phases for initial spin test.

## 52426-10 — Hall sensor harness

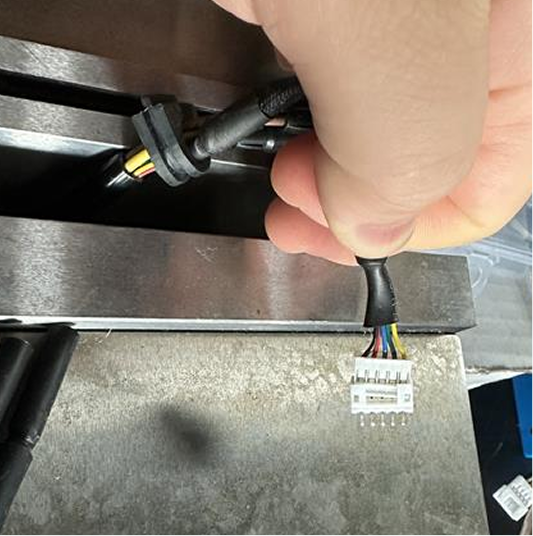
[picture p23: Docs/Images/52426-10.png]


Black=GND, red=V+, blue/green/yellow = hall A/B/C.

## 52426-11 — Wheel interior marking

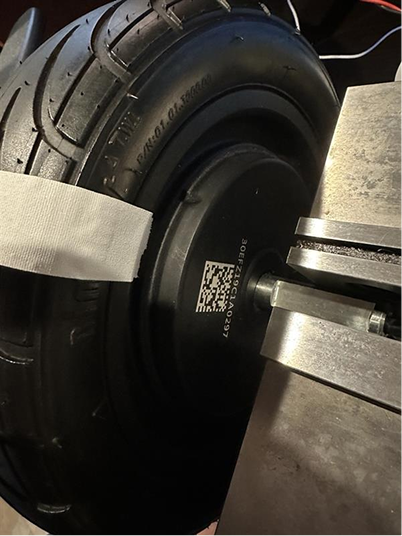
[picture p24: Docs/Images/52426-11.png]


Manufacturing ID: `30EFC19C1A0297`.

## 52426-12 — Wheel sidewall marking

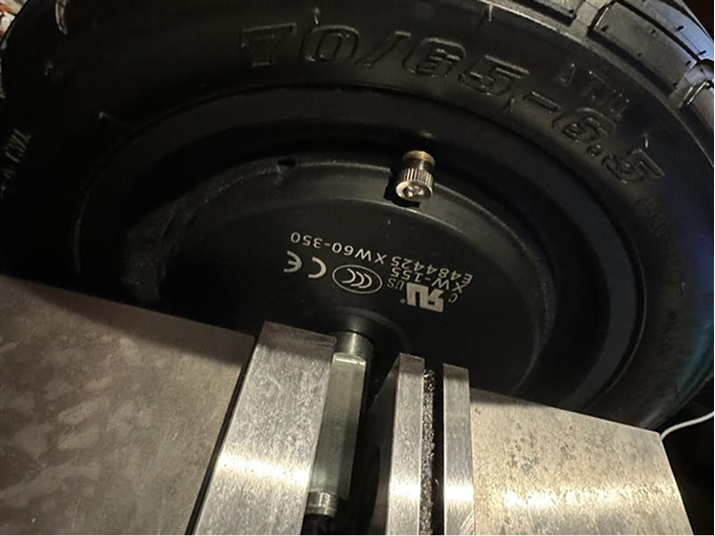
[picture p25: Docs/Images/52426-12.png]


Marking `E484425xw60-350` recorded.

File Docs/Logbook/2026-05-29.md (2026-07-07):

# 2026-05-29 — Preliminary control with Mega and hall calibration

Arduino Mega + analog joystick PPM bench rig; hall sensors wired for motor identification.

---

## 52926-1 — Joystick PPM bench rig

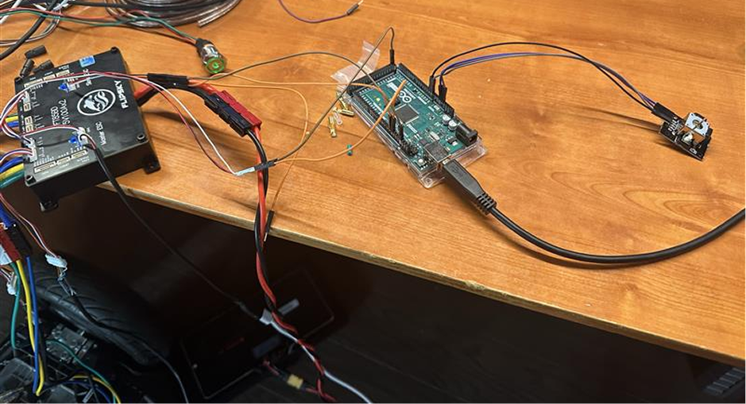
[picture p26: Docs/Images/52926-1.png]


Mega feeds PPM to FT85BD; battery powers ESC.

## 52926-2 — Motor + hall wiring

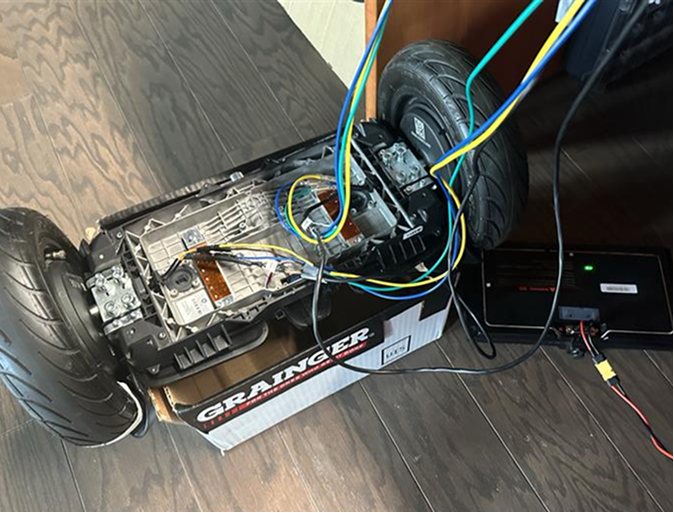
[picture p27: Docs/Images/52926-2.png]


Phase and hall connected for calibration.

## 52926-3 — Hall connector close-up

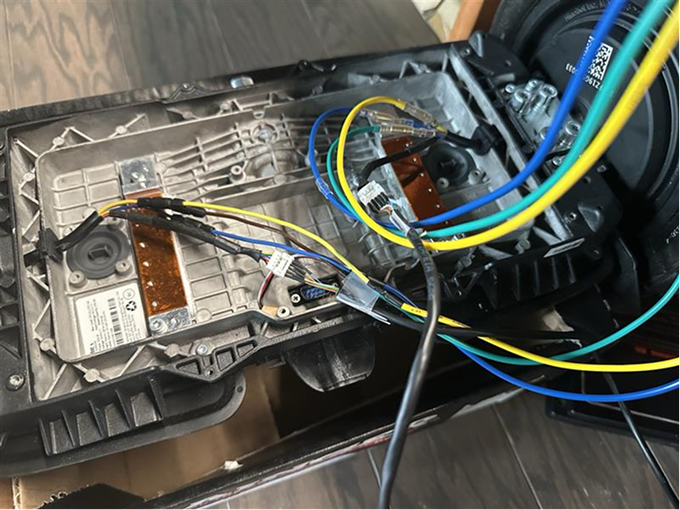
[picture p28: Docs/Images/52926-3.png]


Custom bullet connectors on working hoverboard — primary test platform.

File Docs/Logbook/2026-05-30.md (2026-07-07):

# 2026-05-30 — Stock hoverboard teardown vs test rig

Compare stock assembly to stripped test configuration; RC receiver replaces joystick.

---

## 53026-1 — Stock vs test assembly

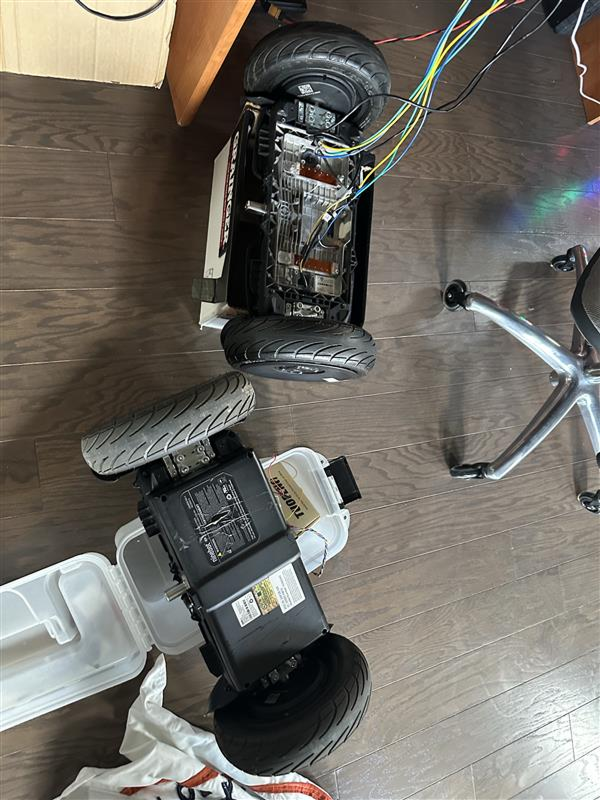
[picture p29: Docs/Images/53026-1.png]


Stock hoverboard with current-sense sandwich vs stripped test rig.

## 53026-2 — Gutted internals

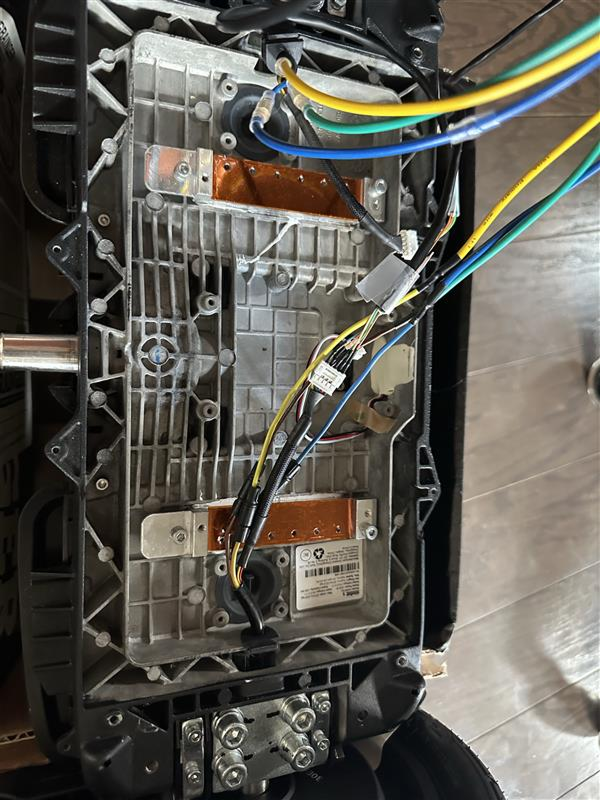
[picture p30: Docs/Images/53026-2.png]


Stock PCBs removed for space and weight.

## 53026-3 — RC receiver on Mega

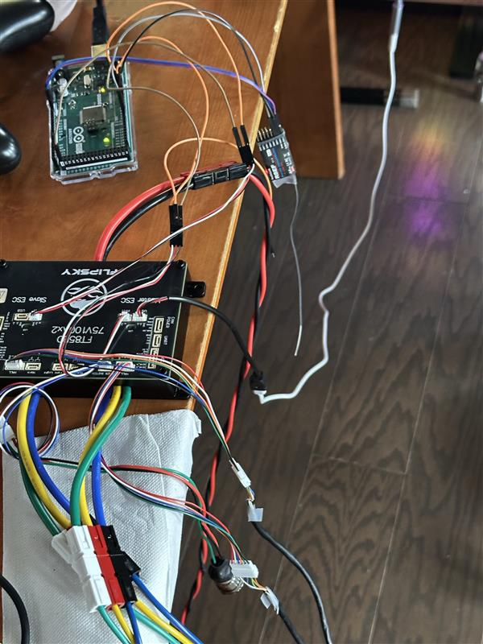
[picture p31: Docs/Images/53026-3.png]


Radiolink receiver replaces analog joystick.

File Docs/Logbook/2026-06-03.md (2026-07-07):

# 2026-06-03 — Harness faults: crimp and cold solder

Intermittent calibration traced to bad green-wire crimp and cold solder on motor lead extensions.

---

## 60326-1 — Bad crimp discovery

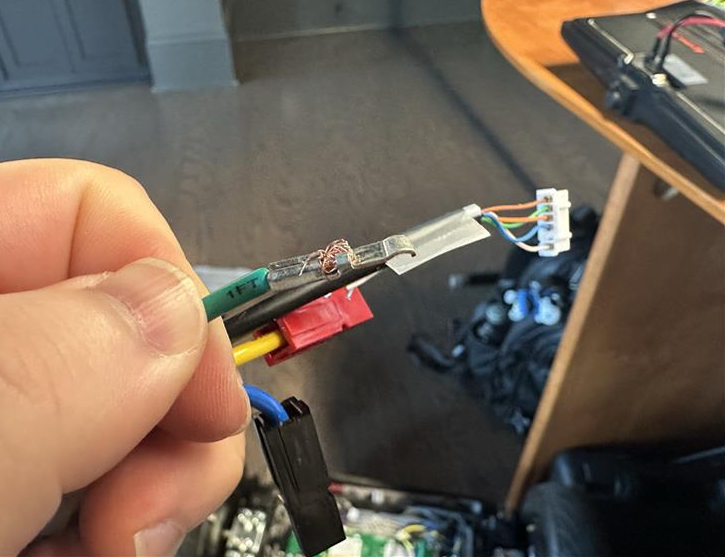
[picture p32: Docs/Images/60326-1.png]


Green wire poor contact caused intermittent tuning — continuity-check all crimps.

## 60326-2 — Two hoverboards compared

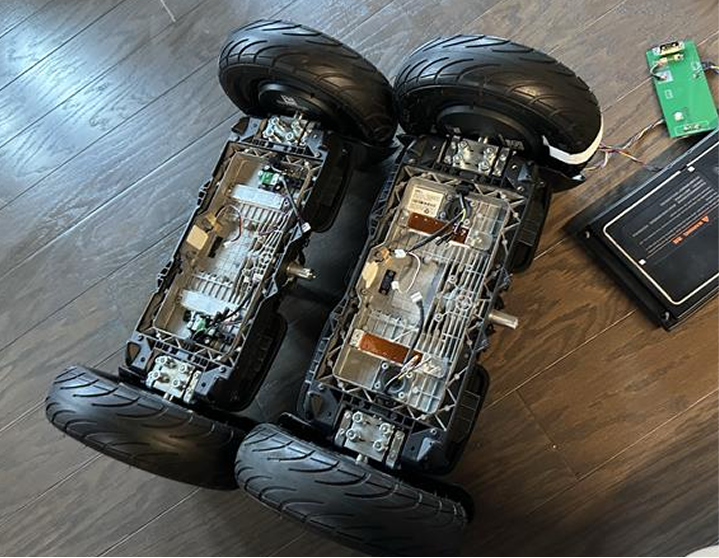
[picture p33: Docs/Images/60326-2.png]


One board later found with damaged hall hardware from prior lab use.

## 60326-3 — Loaded test rig

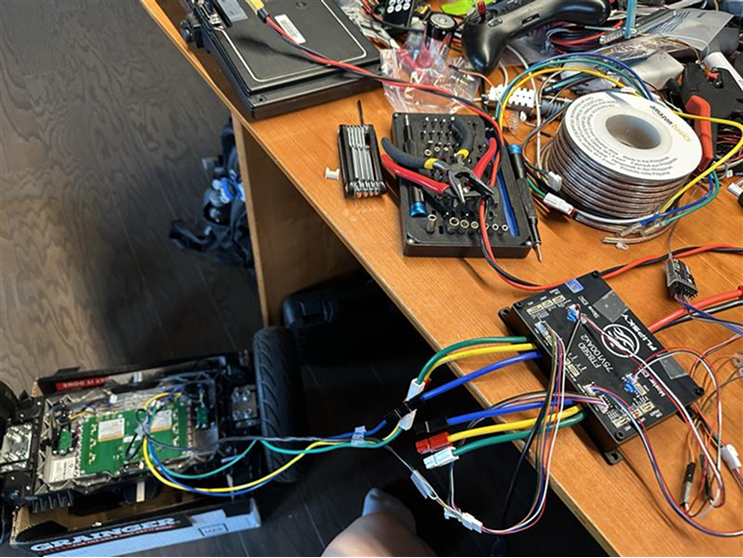
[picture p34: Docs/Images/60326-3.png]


Battery connected for motor runs.

## 60326-4 — Multimeter continuity



Use continuity mode; target near 0 Ω.

## 60326-5 — Problem green wire



Crimp may have grabbed insulation not copper.

## 60326-6 — Motor lead extension



High-temp solder + rosin on thick stranded stock leads.

## 60326-7 — Cold solder joint



Rough unsoldered patches — unreliable connection.

## 60326-8 — Rosin paste rework



Flux before re-flow.

## 60326-9 — Re-flowed joint



Completed joint after rework.

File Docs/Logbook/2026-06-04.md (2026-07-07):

# 2026-06-04 — Chassis integration and wire routing

Wheels mounted under Mecha kit; electronics placement and accessory lighting notes.

---

## 60426-1 — Wheels mounted under chassis



Loaded test: route leads and plan electronics mount.

## 60426-2 — Lead routing options



Harness length allows front or rear exit.

## 60426-3 — Full electronics stack



Battery reposition; ESC ambient brake light; headlight/horn untested.

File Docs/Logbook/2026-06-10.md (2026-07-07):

# 2026-06-10 — Mecha kit rear carrier layout and prototyping

M6 auxiliary holes, seat removal, foam-board and MDF/laser-cut carrier concepts, battery orientation, wire clamping.

---

## 61026-1 — Auxiliary mount holes



Pop-out holes on Mecha kit back expose M6 bolt mounts for add-on plates.

## 61026-2 — Accessing auxiliary holes



Flush cutters remove plastic plugs behind seat.

## 61026-3 — Hardware procurement



Home Depot M6 bolts, washers — multiple lengths for plywood carrier trials.

## 61026-4 — Low flat battery orientation



Lower CoG desired — cart tips forward and scrapes frame under heavy riders.

## 61026-5 — Seat mounting bolts



Four bolt locations under foam seat covers.

## 61026-6 — Seat removed



Measurements for rear electronics CAD carrier.

## 61026-7 — M6 bolts in auxiliary holes



Note lip/clearance for CAD.

## 61026-8 — Foam board layout template



Initial laser-cut / sheet-metal carrier concept.

## 61026-9 — Rear clearance constraint



Minimize rear overhang for Coda storage racks.

## 61026-10 — Preferred battery orientation



Flat, rear, visible charge indicator, plug not crushed by seat.

## 61026-11 — Battery extension check



Ideation — not final.

## 61026-12 — Base board polygon



Triangular carrier with power-button access cutout.

## 61026-13 — Foam board measurements



Bolt spacing and clearances marked.

## 61026-14 — Foam board reverse side



Opposite face layout.

## 61026-15 — Electronics volume study



Battery + ESC + wire bulk on limited rear area.

## 61026-16 — Motor leads to rear



Hoverboard harness routed aft; needs strain relief.

## 61026-17 — Hook-and-loop clamp attempt



3M Velcro failed on cast metal — need new clamp method.

## 61026-18 — Reused hoverboard clamp



Stock bracket + tape grips harness adequately.

## 61026-19 — Harness breakout



Split harness for easier routing.

## 61026-20 — Full foam-board prototype



Carrier concept with all major components.

## 61026-21 — MDF laser-cut minimal carrier



MDF trial — prefer plywood or sheet metal (MDF moisture sensitive).

## 61026-22 — Vertical battery clearance



Seat-to-battery spacing when mounted vertically.

## 61026-23 — Vertical mount perspective



Alternate view of vertical battery clearance.

## 61026-24 — Baseboard not flush



Gap between MDF and Mecha shell — bolts compress plastic over time.

## 61026-25 — 2×4 quick mount prototype



Temporary wood blocks for test mounting.

## 61026-26 — 2×4 battery support concept



Wood sandwich structure ideation.

## 61026-27 — 2×4 lip sandwich



Sandwich lip on battery — woodworking not scalable for fleet upgrade; sheet metal preferred.

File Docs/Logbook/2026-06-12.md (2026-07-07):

# 2026-06-12 — Battery CAD, 3D-printed frame iterations

Fusion 360 battery model, split 3D prints, alignment fixes for stock power port.

---

## 61226-1 — Battery photo for CAD



Ruler reference for Fusion 360 hole layout.

## 61226-2 — Fusion 360 calibration



Image scaled; parallax limits accuracy.

## 61226-3 — Hole and plug layout concept



Battery mount holes and power port cutout check.

## 61226-4 — Split frame for print bed



Two-part print — printer too small for one piece.

## 61226-5 — Print orientation v1



Alternate view of split frame.

## 61226-6 — Bambu slicer prep



~1.5 h per part.

## 61226-7 — MDF + printed insert concept



Iterative tolerance on power plug opening.

## 61226-8 — Reference image mesh



Assembly spacing study — parallax limited usefulness.

## 61226-9 — First print complete



Missing correct screws for stock plug mount.

## 61226-10 — Alignment issues v1



Battery corner holes misaligned; plug off-center.

## 61226-11 — Plug attaches to print



Harness works but frame dimensions wrong.

## 61226-12 — Protruding screws



Wrong screw length — still secures plug for alignment test.

## 61226-13 — Forced fit analysis



Right side pops off; center plug aligns — lengthen frame + fix holes.

## 61226-14 — Custom bullet power tap



Small BMS pins unused — Segway app data not needed.

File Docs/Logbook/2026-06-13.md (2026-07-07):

# 2026-06-13 — Frame interlock and ESC CAD mock-up

Two-part battery frame fit issues; Fusion 360 ESC envelope for rear assembly.

---

## 61326-1 — Split frame length short



Halves lack overlap length — add interlocking fingers.

## 61326-2 — ESC photo for CAD



Reference capture for ESC mock-up model.

## 61326-3 — ESC CAD mock-up



Heights, clearances, and lead wire bandwidth for full assembly.

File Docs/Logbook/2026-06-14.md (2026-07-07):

# 2026-06-14 — Battery frame v2 alignment

Updated 3D-printed battery frame; minor gap between halves accepted for now.

---

## 61426-1 — Frame v2 overview



Updated alignment; small gap between halves — forced fit for now.

## 61426-2 — Plug fit close-up



Stock plug seats correctly in printed frame.

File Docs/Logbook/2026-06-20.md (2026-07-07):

# 2026-06-20 — Battery support brackets and ESC placement

Carbon-fiber PLA vertical battery supports; CAD full assembly and seat angle measurements.

---

## 62026-1 — Battery support prototypes



Slot-in supports for fore/aft battery position trials (CF-PLA, wood-screwed to plywood).

## 62026-2 — Supports side view



Battery seated in printed adapters.

## 62026-3 — Support performance



Small prints proved surprisingly rigid under battery mass.

## 62026-4 — ESC placement ideation



Compact stack: ESC on battery back, Arduino to the side.

## 62026-5 — Seat angle scratch measurements



Seat back ~67.8° from horizontal — battery must sit below this.

## 62026-6 — Full CAD assembly



Visualized target rear packaging.

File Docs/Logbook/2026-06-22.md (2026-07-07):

# 2026-06-22 — First rear-panel integrated prototype

Plywood carrier with ESC, Mega, RC receiver; ready for first rider-on tests.

---

## 62226-1 — Electronics on plywood base



Wood-screw mounted ESC, Mega, Radiolink RX; hall wires connected.

## 62226-2 — Battery plugged in



Plug clearance from seat back — ready for loaded drive tests.

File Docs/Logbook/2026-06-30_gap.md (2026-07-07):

# 2026-06-22 → 2026-06-30 — Progress gap and software transition

Family emergency and exams paused hardware work; informal firmware iteration moved toward GitHub.

---

## Context (no images)

Hardware progress paused roughly **2026-06-22 through 2026-06-30** due to family emergency and exams. Firmware work continued but was not well versioned.

- Initial drive tests used simple **PPM** control.
- Planned migration to **UART telemetry** for battery voltage, currents, RPM, and time-series logging.
- Repository consolidation on **GitHub** began to track software properly.

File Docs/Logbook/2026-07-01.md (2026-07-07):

# 2026-07-01 — UART bring-up and logic-level discovery

Organized engineering logs; UART telemetry first success; 3.3 V ESC logic vs 5 V Mega mistake.

---

## 70126-1 — Engineering log organization



Pictures uploaded; dictation workflow for GitHub-linked documentation.

## 70126-2 — UART work begins



Attempt to read battery voltage from cart over UART.

## 70126-3 — 3.3 V logic discovery



FT85BD UART is 3.3 V — Mega 5 V connection was a wiring mistake; damage assessment needed.

## 70126-4 — Oscilloscope probe



NI myDAQ ~3.3 V stable on ESC TX — initial sign of life.

## 70126-5 — Dual ESC telemetry



Master 101 and slave 102 report matching pack voltage, RPM, current, and fault codes.

## 70126-6 — Telemetry under PPM load



Under PPM throttle: ERPM, battery current, motor current visible; no temperature or encoder angle from hall-only setup.

## 70126-7 — Flipsky control setup screenshot



Throttle response level 2; signal ramp pos/neg; input type set UART (later found UART read-only on hobby FT85BD — PPM still required for drive).

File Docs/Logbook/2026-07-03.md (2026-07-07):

# 2026-07-03 — Flipsky tool tuning and motor fault discovery

Hall startup, ERPM threshold 400, current vs differential instability; motor 1 hall fault on lab-tested hoverboard.

---

## 70326-1 — VESC tool comparison



Original VESC tool vs simplified Flipsky package — far more options on VESC variant.

## 70326-2 — Motor startup settings



Hall start; direction set in tool not firmware; zero-duty keep-output (brake not coast).

## 70326-3 — Observer ERPM threshold 400



Motors struggle below ~400 ERPM in speed mode testing.

## 70326-4 — Max current limits



60 A/motor bench — adequate hill climb with 200 lb payload but **current mode unstable** for differential drive.

## 70326-5 — Control setup page



Throttle response L2, deadband, ramp times; **PPM required** — UART command not viable on hobby FT85BD.

## 70326-6 — Auto-calibrate fault



Motor 1: hall sensor code **6**, startup IPD not Hall — damaged hall on lab-tested hoverboard.

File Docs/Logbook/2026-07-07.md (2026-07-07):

# 2026-07-07 — Duty-cycle mode, shudder debug, SD logging prep

Duty control smooth at low ERPM; current mode spin-outs; speed mode buzz; diagnostic/logger firmware and repo updates.

---

## Session notes (duty-cycle evaluation)

Switched primary tuning focus to **duty-cycle control**:

| Mode | Observation |
|---|---|
| **Current** | Strong low-speed torque but **unstable differential drive** — spin-outs with rider; wiped out multiple times. |
| **Speed** | Stable differential behavior but **buzz/hum and hang-up below ~400 ERPM**. |
| **Duty cycle** | **Smooth low-ERPM crawl** (~400 range) without speed-mode lock-up; current priority for rider safety. |

### Debug checklist (in progress)

- Battery sag and stock BMS trip points
- Logic-level noise on dual UART
- Metal screw shorts through plywood mounts
- Whether higher-discharge pack needed for duty mode

### Firmware / repo

- Added diagnostic tools and **UART telemetry SD logger** (`UartTelemetryLogger_NanoESP32`)
- Steering gain at low RPM still weak in `UartSpeedController_NanoESP32` — on TODO list

## 70726-1 — Alternate battery research



48 V 20 Ah pack specs (AI-assisted) vs stock Segway ~15 A BMS limit — conjecture.

## 70726-2 — Product page reference



Electrical parameters for Flipsky battery setup.

## 70726-3 — CAD spacer request



Requested Mecha kit current-sensor spacer CAD from course staff to skip re-measure.

## 70726-4 — EV Grid summer project files



Footprint templates for ESC and MCU rear-panel integration.

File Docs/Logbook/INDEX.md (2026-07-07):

# Engineering Logbook Index

Dated entries transcribed from video dictation (`Docs/Notes/2026-07-07 16-58-03.mp4`, gitignored).
Source transcript: [`_source/2026-07-07_video_transcript.txt`](_source/2026-07-07_video_transcript.txt)

| Date | Session | Images | File |
|---|---|---|---|
| 2026-05-22 | Stock battery connector and power distribution | 9 | [2026-05-22.md](2026-05-22.md) |
| 2026-05-24 | Motor phase harnesses and first ESC power-on | 12 | [2026-05-24.md](2026-05-24.md) |
| 2026-05-29 | Preliminary control with Mega and hall calibration | 3 | [2026-05-29.md](2026-05-29.md) |
| 2026-05-30 | Stock hoverboard teardown vs test rig | 3 | [2026-05-30.md](2026-05-30.md) |
| 2026-06-03 | Harness faults: crimp and cold solder | 9 | [2026-06-03.md](2026-06-03.md) |
| 2026-06-04 | Chassis integration and wire routing | 3 | [2026-06-04.md](2026-06-04.md) |
| 2026-06-10 | Mecha kit rear carrier layout and prototyping | 27 | [2026-06-10.md](2026-06-10.md) |
| 2026-06-12 | Battery CAD, 3D-printed frame iterations | 14 | [2026-06-12.md](2026-06-12.md) |
| 2026-06-13 | Frame interlock and ESC CAD mock-up | 3 | [2026-06-13.md](2026-06-13.md) |
| 2026-06-14 | Battery frame v2 alignment | 2 | [2026-06-14.md](2026-06-14.md) |
| 2026-06-20 | Battery support brackets and ESC placement | 6 | [2026-06-20.md](2026-06-20.md) |
| 2026-06-22 | First rear-panel integrated prototype | 2 | [2026-06-22.md](2026-06-22.md) |
| 2026-06-30_gap | Progress gap and software transition | 0 | [2026-06-30_gap.md](2026-06-30_gap.md) |
| 2026-07-01 | UART bring-up and logic-level discovery | 7 | [2026-07-01.md](2026-07-01.md) |
| 2026-07-03 | Flipsky tool tuning and motor fault discovery | 6 | [2026-07-03.md](2026-07-03.md) |
| 2026-07-07 | Duty-cycle mode, shudder debug, SD logging prep | 4 | [2026-07-07.md](2026-07-07.md) |

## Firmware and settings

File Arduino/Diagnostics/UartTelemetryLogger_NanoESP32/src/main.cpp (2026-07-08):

/*
 * UartTelemetryLogger_NanoESP32
 *
 * Dual-UART FT85BD telemetry logger + RC drive for Arduino Nano ESP32.
 * Writes CSV to Adafruit microSD SPI breakout while driving the cart so
 * stutter / low-speed behavior can be captured and analyzed.
 *
 * UART (dual, same as UartSpeedController_NanoESP32):
 *   Serial1 master  D8 RX / D9 TX   ID 101
 *   Serial2 slave   D4 RX / D5 TX   ID 102
 *
 * RC PWM in:
 *   Throttle D2, Steering D3
 *
 * PPM drive out (default — proven on meka cart):
 *   Master D6 -> COMM PPM, Slave D10 -> COMM PPM
 *   ESC tool: Input Signal Type = PPM
 *
 * microSD (Adafruit breakout, SPI):
 *   CS   -> D7
 *   MOSI -> D11
 *   MISO -> D12
 *   SCK  -> D13
 */

#include <Arduino.h>
#include <SPI.h>
#include <SD.h>
#include <driver/gpio.h>
#include "FlipskyUart.h"

static const char FIRMWARE_VERSION[] = "2.3.0";

// =====================
// DRIVE OUTPUT MODE
// =====================
enum class DriveMode : uint8_t {
  PPM,
  UART_CMD32,
  UART_CURRENT,
};

static const bool ENABLE_DRIVE = true;
static const DriveMode DRIVE_MODE = DriveMode::PPM;

// =====================
// SD CARD (Adafruit microSD SPI breakout)
// =====================
static const int SD_CS_PIN = D7;
static const int SD_SCK_PIN = D13;
static const int SD_MISO_PIN = D12;
static const int SD_MOSI_PIN = D11;

// =====================
// PINS
// =====================
static const int THROTTLE_IN_PIN = D2;
static const int STEERING_IN_PIN = D3;
static const int MASTER_RX_PIN = D8;
static const int MASTER_TX_PIN = D9;
static const int SLAVE_RX_PIN = D4;
static const int SLAVE_TX_PIN = D5;
static const int MASTER_PPM_PIN = D6;
static const int SLAVE_PPM_PIN = D10;

static const unsigned long ESC_BAUD = 115200;
static const uint8_t MASTER_ESC_ID = 101;
static const uint8_t SLAVE_ESC_ID = 102;

static const int PPM_MID_US = 1500;
static const int PPM_FORWARD_RANGE_US = 400;
static const int PPM_REVERSE_RANGE_US = 144;
static const int PPM_FRAME_US = 20000;
static const int PPM_INTER_FRAME_GAP_US = 400;

static const float MAX_FORWARD_CURRENT_A = 40.0f;
static const float MAX_REVERSE_CURRENT_A = 15.0f;
static const float CURRENT_TO_MICROA = 1000000.0f;

static const bool INVERT_THROTTLE = true;
static const bool INVERT_STEERING = false;
static const bool INVERT_MASTER = false;
static const bool INVERT_SLAVE = false;

static const int RC_DEADBAND_US = 60;
static const float CMD_ZERO_THRESHOLD = 0.03f;
static const float THROTTLE_EXPO = 0.60f;
static const float STEERING_EXPO = 0.50f;
static const float THROTTLE_RAMP_STEP = 0.015f;
static const float THROTTLE_BRAKE_RAMP_STEP = 0.06f;
static const float STEERING_RAMP_STEP = 0.020f;
static const float SPEED_STEERING_GAIN = 0.30f;
static const float MAX_TURN_REDUCTION = 0.75f;
static const bool ENABLE_PIVOT_STEERING = false;
static const float PIVOT_THROTTLE_THRESHOLD = 0.06f;
static const float PIVOT_STEERING_GAIN = 0.18f;
static const float PIVOT_EXPO = 0.75f;
static const float PIVOT_RAMP_STEP = 0.010f;
static const float MASTER_PIVOT_GAIN_TRIM = 1.00f;
static const float SLAVE_PIVOT_GAIN_TRIM = 1.00f;
static const unsigned long SIGNAL_TIMEOUT_MS = 300;
static const int RC_PWM_MIN_US = 850;
static const int RC_PWM_MAX_US = 2150;

static const unsigned long POLL_INTERVAL_MS = 125;
static const unsigned long RESPONSE_WAIT_MS = 25;
static const unsigned long ALIVE_INTERVAL_MS = 1000;
static const unsigned long STATUS_INTERVAL_MS = 5000;
static const unsigned long FLUSH_INTERVAL_MS = 3000;
static const uint16_t FLUSH_EVERY_ROWS = 32;

// Logged control_state values (see CSV header comments).
static const uint8_t CTRL_STOP_NO_THROTTLE = 0;
static const uint8_t CTRL_NORMAL_DRIVE = 1;
static const uint8_t CTRL_STEERING_TIMEOUT = 2;
static const uint8_t CTRL_FAILSAFE_STOP = 3;

static const int32_t RC_AGE_NEVER_SEEN = -1;

class GpioPpmOut {
public:
  bool begin(int arduinoPin) {
    arduinoPin_ = arduinoPin;
    gpio_ = digitalPinToGPIONumber(arduinoPin);
    if (gpio_ < 0) {
      return false;
    }
    pinMode(arduinoPin, OUTPUT);
    gpio_set_level((gpio_num_t)gpio_, 0);
    pulseUs_ = PPM_MID_US;
    return true;
  }

  void writeMicroseconds(int pulseUs) {
    pulseUs_ = constrain(pulseUs, 500, 2500);
  }

  int pulseUs() const { return pulseUs_; }

  void emitPulse() const {
    if (gpio_ < 0) {
      return;
    }
    gpio_set_level((gpio_num_t)gpio_, 1);
    delayMicroseconds(pulseUs_);
    gpio_set_level((gpio_num_t)gpio_, 0);
  }

private:
  int arduinoPin_ = -1;
  int gpio_ = -1;
  int pulseUs_ = PPM_MID_US;
};

enum class TelState : uint8_t { Idle, WaitMaster, WaitSlave };

struct EscSample {
  bool valid = false;
  int32_t rpm = 0;
  float duty = 0.0f;
  float motorCurrent = 0.0f;
  float inputCurrent = 0.0f;
  float vIn = 0.0f;
  uint8_t faultCode = 0;
};

FlipskyUart masterEsc;
FlipskyUart slaveEsc;
GpioPpmOut masterPpm;
GpioPpmOut slavePpm;

EscSample pendingMaster;
EscSample pendingSlave;

File logFile;
char logPath[32] = "";
bool sdReady = false;
uint32_t rowsWritten = 0;
uint16_t rowsSinceFlush = 0;

unsigned long lastPollMs = 0;
unsigned long lastAliveMs = 0;
unsigned long lastStatusMs = 0;
unsigned long lastFlushMs = 0;
unsigned long sessionStartMs = 0;
unsigned long telWaitStartMs = 0;

TelState telState = TelState::Idle;

static int throttlePulse = 1500;
static int steeringPulse = 1500;
static unsigned long lastThrottleUpdateUs = 0;
static unsigned long lastSteeringUpdateUs = 0;
static uint32_t throttleValidCount = 0;
static uint32_t steeringValidCount = 0;
static bool throttleEver = false;
static bool steeringEver = false;
static uint8_t rcPollNext = 0;

static float throttleCurrent = 0;
static float steeringCurrent = 0;
static float pivotCurrent = 0;

static int logThrUs = 1500;
static int logStrUs = 1500;
static float logThrottleNorm = 0.0f;
static float logSteeringNorm = 0.0f;
static float logLeftMix = 0.0f;
static float logRightMix = 0.0f;
static int logMstPpmUs = PPM_MID_US;
static int logSlvPpmUs = PPM_MID_US;
static int32_t logThrottleAgeMs = RC_AGE_NEVER_SEEN;
static int32_t logSteeringAgeMs = RC_AGE_NEVER_SEEN;
static uint8_t logThrottleSignalValid = 0;
static uint8_t logSteeringSignalValid = 0;
static uint8_t logThrottleEverSeen = 0;
static uint8_t logSteeringEverSeen = 0;
static uint8_t logStopCommanded = 0;
static uint8_t logControlState = CTRL_STOP_NO_THROTTLE;

static unsigned long lastEsc1TelemetryMs = 0;
static unsigned long lastEsc2TelemetryMs = 0;
static unsigned long lastLogRowMs = 0;

// =====================
// HELPERS
// =====================
static void waitForUsbSerial() {
  const unsigned long deadline = millis() + 3000;
  while (!Serial && millis() < deadline) {
    delay(10);
  }
}

static const __FlashStringHelper *driveModeLabel() {
  switch (DRIVE_MODE) {
    case DriveMode::PPM:
      return F("PPM D6/D10");
    case DriveMode::UART_CMD32:
      return F("UART cmd32");
    case DriveMode::UART_CURRENT:
      return F("UART current");
  }
  return F("unknown");
}

static const char *faultName(uint8_t code) {
  switch (code) {
    case 0:
      return "NONE";
    case 1:
      return "OVER_VOLTAGE";
    case 2:
      return "UNDER_VOLTAGE";
    case 3:
      return "DRV";
    case 4:
      return "ABS_OVER_CURRENT";
    case 5:
      return "OVER_TEMP_FET";
    case 6:
      return "OVER_TEMP_MOTOR";
    case 7:
      return "GATE_DRIVER_OVER_VOLTAGE";
    case 8:
      return "GATE_DRIVER_UNDER_VOLTAGE";
    case 9:
      return "MCU_UNDER_VOLTAGE";
    case 10:
      return "BOOTING_FROM_WATCHDOG_RESET";
    case 11:
      return "ENCODER_SPI";
    case 12:
      return "ENCODER_SINCOS_BELOW_MIN_AMPLITUDE";
    case 13:
      return "ENCODER_SINCOS_ABOVE_MAX_AMPLITUDE";
    case 14:
      return "FLASH_CORRUPTION";
    case 15:
      return "HIGH_OFFSET_CURRENT_SENSOR_1";
    case 16:
      return "HIGH_OFFSET_CURRENT_SENSOR_2";
    case 17:
      return "HIGH_OFFSET_CURRENT_SENSOR_3";
    case 18:
      return "UNBALANCED_CURRENTS";
    case 19:
      return "BRK";
    case 20:
      return "RESOLVER_LOT";
    case 21:
      return "RESOLVER_DOS";
    case 22:
      return "RESOLVER_LOS";
    case 23:
      return "FLASH_CORRUPTION_APP_CFG";
    case 24:
      return "FLASH_CORRUPTION_MC_CFG";
    case 25:
      return "ENCODER_NO_MAGNET";
    case 26:
      return "ENCODER_MAGNET_TOO_STRONG";
    case 27:
      return "PHASE_FILTER";
    case 28:
      return "ENCODER_FAULT";
    case 29:
      return "LV_OUTPUT_FAULT";
    case 30:
      return "ENCODER_SLIP";
    case 31:
      return "OVERSPEED";
    case 32:
      return "UNDERSPEED";
    case 33:
      return "ABS_OVERSPEED";
    default:
      return "UNKNOWN";
  }
}

static void captureEscSample(const FlipskyUart &esc, EscSample &out,
                             unsigned long &lastUpdateMs) {
  out.valid = true;
  out.rpm = esc.erpm();
  out.duty = esc.dutyCycle();
  out.motorCurrent = esc.motorCurrent();
  out.inputCurrent = esc.inputCurrent();
  out.vIn = esc.inputVoltage();
  out.faultCode = esc.faultCode();
  lastUpdateMs = millis();
}

static void printCsvFloat(bool valid, float value, uint8_t decimals) {
  if (!valid) {
    return;
  }
  logFile.print(value, decimals);
}

static void printCsvInt(bool valid, int32_t value) {
  if (!valid) {
    return;
  }
  logFile.print(value);
}

static void printCsvEscFields(const EscSample &sample) {
  printCsvInt(sample.valid, sample.rpm);
  logFile.print(',');
  printCsvFloat(sample.valid, sample.duty, 5);
  logFile.print(',');
  printCsvFloat(sample.valid, sample.motorCurrent, 4);
  logFile.print(',');
  printCsvFloat(sample.valid, sample.inputCurrent, 4);
  logFile.print(',');
  printCsvFloat(sample.valid, sample.vIn, 3);
  logFile.print(',');
  if (sample.valid) {
    logFile.print(sample.faultCode);
    logFile.print(',');
    logFile.print(faultName(sample.faultCode));
  } else {
    logFile.print(',');
  }
}

static unsigned long escAgeMs(unsigned long lastUpdateMs) {
  if (lastUpdateMs == 0) {
    return 0;
  }
  return millis() - lastUpdateMs;
}

static void pollEscPorts() {
  masterEsc.poll();
  slaveEsc.poll();
}

static void servicePpmOutputs() {
  const unsigned long frameStartUs = micros();
  masterPpm.emitPulse();
  delayMicroseconds(PPM_INTER_FRAME_GAP_US);
  slavePpm.emitPulse();
  const unsigned long elapsedUs = micros() - frameStartUs;
  if (elapsedUs < (unsigned long)PPM_FRAME_US) {
    delayMicroseconds((unsigned int)(PPM_FRAME_US - elapsedUs));
  }
}

static void pollOneRcChannel() {
  const int pin = (rcPollNext == 0) ? THROTTLE_IN_PIN : STEERING_IN_PIN;
  rcPollNext ^= 1;

  const unsigned long width = pulseInLong(pin, HIGH, 25000);
  if (width < (unsigned long)RC_PWM_MIN_US ||
      width > (unsigned long)RC_PWM_MAX_US) {
    return;
  }

  const unsigned long nowUs = micros();
  if (pin == THROTTLE_IN_PIN) {
    throttlePulse = (int)width;
    lastThrottleUpdateUs = nowUs;
    throttleEver = true;
    throttleValidCount++;
  } else {
    steeringPulse = (int)width;
    lastSteeringUpdateUs = nowUs;
    steeringEver = true;
    steeringValidCount++;
  }
}

static float pulseToNorm(int pulse, bool invert) {
  const int centered = pulse - 1500;
  if (abs(centered) < RC_DEADBAND_US) {
    return 0.0f;
  }
  float x = constrain(centered / 500.0f, -1.0f, 1.0f);
  if (invert) {
    x = -x;
  }
  return x;
}

static float applyExpo(float x, float expo) {
  return (1.0f - expo) * x + expo * x * x * x;
}

static float rampToward(float current, float target, float step) {
  if (current < target) {
    return min(current + step, target);
  }
  if (current > target) {
    return max(current - step, target);
  }
  return current;
}

static float rampThrottle(float current, float target) {
  const bool braking =
      fabsf(target) < fabsf(current) ||
      (fabsf(target) < CMD_ZERO_THRESHOLD && fabsf(current) > CMD_ZERO_THRESHOLD);
  return rampToward(current, target,
                    braking ? THROTTLE_BRAKE_RAMP_STEP : THROTTLE_RAMP_STEP);
}

static int32_t limitCurrentMicroA(float cmd) {
  float amps = cmd * MAX_FORWARD_CURRENT_A;
  if (cmd < 0) {
    amps = cmd * MAX_REVERSE_CURRENT_A;
  }
  return (int32_t)(amps * CURRENT_TO_MICROA);
}

static uint8_t gearForCommand(float cmd) {
  const float absCmd = fabsf(cmd);
  if (absCmd < CMD_ZERO_THRESHOLD) {
    return FTESC_GEAR_NEUTRAL;
  }
  if (cmd < 0) {
    return FTESC_GEAR_REVERSE;
  }
  if (absCmd < 0.34f) {
    return FTESC_GEAR_FORWARD_LOW;
  }
  if (absCmd < 0.67f) {
    return FTESC_GEAR_FORWARD_MED;
  }
  return FTESC_GEAR_FORWARD_HIGH;
}

static int32_t magnitudeMicroA(float cmd) {
  float amps = fabsf(cmd) * MAX_FORWARD_CURRENT_A;
  if (cmd < 0) {
    amps = fabsf(cmd) * MAX_REVERSE_CURRENT_A;
  }
  return (int32_t)(amps * CURRENT_TO_MICROA);
}

static int cmdToPpmUs(float cmd) {
  if (fabsf(cmd) < CMD_ZERO_THRESHOLD) {
    return PPM_MID_US;
  }
  if (cmd > 0) {
    return PPM_MID_US + (int)(cmd * PPM_FORWARD_RANGE_US);
  }
  return PPM_MID_US + (int)(cmd * PPM_REVERSE_RANGE_US);
}

static void computeWheelCommands(float &masterCmd, float &slaveCmd) {
  const float throttleAbs = fabsf(throttleCurrent);
  const float steeringAbs = fabsf(steeringCurrent);
  const float steer = steeringCurrent;

  if (ENABLE_PIVOT_STEERING && throttleAbs < PIVOT_THROTTLE_THRESHOLD &&
      steeringAbs > 0.08f) {
    const float pivotTarget =
        applyExpo(steer, PIVOT_EXPO) * PIVOT_STEERING_GAIN;
    pivotCurrent = rampToward(pivotCurrent, pivotTarget, PIVOT_RAMP_STEP);
    masterCmd = pivotCurrent * MASTER_PIVOT_GAIN_TRIM;
    slaveCmd = -pivotCurrent * SLAVE_PIVOT_GAIN_TRIM;
  } else {
    pivotCurrent = rampToward(pivotCurrent, 0.0f, PIVOT_RAMP_STEP);

    float turn = steeringAbs * SPEED_STEERING_GAIN;
    turn = constrain(turn, 0.0f, MAX_TURN_REDUCTION);

    const float outsideCmd = throttleCurrent;
    const float insideCmd = throttleCurrent * (1.0f - turn);

    if (steer > 0.05f) {
      masterCmd = outsideCmd;
      slaveCmd = insideCmd;
    } else if (steer < -0.05f) {
      masterCmd = insideCmd;
      slaveCmd = outsideCmd;
    } else {
      masterCmd = throttleCurrent;
      slaveCmd = throttleCurrent;
    }
  }

  if (INVERT_MASTER) {
    masterCmd = -masterCmd;
  }
  if (INVERT_SLAVE) {
    slaveCmd = -slaveCmd;
  }
}

static void updateCommandLogSnapshot(float masterCmd, float slaveCmd) {
  logLeftMix = masterCmd;
  logRightMix = slaveCmd;
  if (DRIVE_MODE == DriveMode::PPM) {
    logMstPpmUs = cmdToPpmUs(masterCmd);
    logSlvPpmUs = cmdToPpmUs(slaveCmd);
  }
}

static void sendStop() {
  if (DRIVE_MODE == DriveMode::PPM) {
    masterPpm.writeMicroseconds(PPM_MID_US);
    slavePpm.writeMicroseconds(PPM_MID_US);
  } else if (DRIVE_MODE == DriveMode::UART_CMD32) {
    masterEsc.setCurrentGearAndObtain(FTESC_GEAR_NEUTRAL, 0);
    slaveEsc.setCurrentGearAndObtain(FTESC_GEAR_NEUTRAL, 0);
  } else {
    masterEsc.setCurrent(0);
    slaveEsc.setCurrent(0);
  }
  throttleCurrent = 0;
  steeringCurrent = 0;
  pivotCurrent = 0;
  logLeftMix = 0.0f;
  logRightMix = 0.0f;
  logMstPpmUs = PPM_MID_US;
  logSlvPpmUs = PPM_MID_US;
}

static void sendWheelDrive(float masterCmd, float slaveCmd) {
  updateCommandLogSnapshot(masterCmd, slaveCmd);

  if (DRIVE_MODE == DriveMode::PPM) {
    masterPpm.writeMicroseconds(logMstPpmUs);
    slavePpm.writeMicroseconds(logSlvPpmUs);
    return;
  }

  logMstPpmUs = PPM_MID_US;
  logSlvPpmUs = PPM_MID_US;

  if (DRIVE_MODE == DriveMode::UART_CMD32) {
    masterEsc.setCurrentGearAndObtain(gearForCommand(masterCmd),
                                      magnitudeMicroA(masterCmd));
    slaveEsc.setCurrentGearAndObtain(gearForCommand(slaveCmd),
                                     magnitudeMicroA(slaveCmd));
    return;
  }

  masterEsc.setCurrent(limitCurrentMicroA(masterCmd));
  slaveEsc.setCurrent(limitCurrentMicroA(slaveCmd));
}

static bool initSdCard() {
  SPI.begin(SD_SCK_PIN, SD_MISO_PIN, SD_MOSI_PIN, SD_CS_PIN);
  if (!SD.begin(SD_CS_PIN)) {
    return false;
  }

  for (uint16_t n = 1; n < 1000; n++) {
    snprintf(logPath, sizeof(logPath), "/tel_%03u.csv", n);
    if (!SD.exists(logPath)) {
      return true;
    }
  }

  snprintf(logPath, sizeof(logPath), "/tel_ovf.csv");
  return true;
}

static bool openLogFile() {
  logFile = SD.open(logPath, FILE_WRITE);
  if (!logFile) {
    return false;
  }

  logFile.println(F("# GT-EV-Testbed UART telemetry + drive log"));
  logFile.print(F("# session_start_ms,"));
  logFile.println(sessionStartMs);
  logFile.print(F("# master_id,"));
  logFile.print(MASTER_ESC_ID);
  logFile.print(F(" (esc1),slave_id,"));
  logFile.print(SLAVE_ESC_ID);
  logFile.println(F(" (esc2)"));
  logFile.print(F("# firmware,"));
  logFile.println(FIRMWARE_VERSION);
  logFile.print(F("# poll_ms="));
  logFile.print(POLL_INTERVAL_MS);
  logFile.print(F(",drive="));
  logFile.println(driveModeLabel());
  logFile.println(
      F("# control_state: 0=STOP_NO_THROTTLE 1=NORMAL_DRIVE "
        "2=STEERING_TIMEOUT 3=FAILSAFE_STOP"));
  logFile.println(
      F("# throttle_age_ms,steering_age_ms: -1 if channel never seen"));
  logFile.println(
      F("# stop_commanded: 1=firmware neutral due to invalid throttle only"));
  logFile.println(
      F("time_ms,loop_dt_ms,"
        "throttle_us,steering_us,throttle_norm,steering_norm,left_mix,right_mix,"
        "master_ppm_us,slave_ppm_us,"
        "throttle_age_ms,steering_age_ms,"
        "throttle_signal_valid,steering_signal_valid,"
        "throttle_ever_seen,steering_ever_seen,"
        "stop_commanded,control_state,"
        "esc1_last_update_age_ms,esc2_last_update_age_ms,"
        "esc1_rpm,esc1_duty,esc1_motor_current,esc1_input_current,esc1_vin,"
        "esc1_fault_code,esc1_fault_name,"
        "esc2_rpm,esc2_duty,esc2_motor_current,esc2_input_current,esc2_vin,"
        "esc2_fault_code,esc2_fault_name"));
  logFile.flush();
  return true;
}

static void flushLogIfNeeded(bool force) {
  if (!sdReady || !logFile) {
    return;
  }

  const unsigned long now = millis();
  if (force || rowsSinceFlush >= FLUSH_EVERY_ROWS ||
      (now - lastFlushMs) >= FLUSH_INTERVAL_MS) {
    logFile.flush();
    rowsSinceFlush = 0;
    lastFlushMs = now;
  }
}

static void logCombinedRow(const EscSample &esc1, const EscSample &esc2) {
  if (!sdReady || !logFile) {
    return;
  }

  const unsigned long now = millis();
  const unsigned long loopDtMs =
      (lastLogRowMs == 0) ? 0 : (now - lastLogRowMs);
  lastLogRowMs = now;

  logFile.print(now);
  logFile.print(',');
  logFile.print(loopDtMs);
  logFile.print(',');
  logFile.print(logThrUs);
  logFile.print(',');
  logFile.print(logStrUs);
  logFile.print(',');
  logFile.print(logThrottleNorm, 4);
  logFile.print(',');
  logFile.print(logSteeringNorm, 4);
  logFile.print(',');
  logFile.print(logLeftMix, 4);
  logFile.print(',');
  logFile.print(logRightMix, 4);
  logFile.print(',');
  logFile.print(logMstPpmUs);
  logFile.print(',');
  logFile.print(logSlvPpmUs);
  logFile.print(',');
  logFile.print(logThrottleAgeMs);
  logFile.print(',');
  logFile.print(logSteeringAgeMs);
  logFile.print(',');
  logFile.print(logThrottleSignalValid);
  logFile.print(',');
  logFile.print(logSteeringSignalValid);
  logFile.print(',');
  logFile.print(logThrottleEverSeen);
  logFile.print(',');
  logFile.print(logSteeringEverSeen);
  logFile.print(',');
  logFile.print(logStopCommanded);
  logFile.print(',');
  logFile.print(logControlState);
  logFile.print(',');
  logFile.print(escAgeMs(lastEsc1TelemetryMs));
  logFile.print(',');
  logFile.print(escAgeMs(lastEsc2TelemetryMs));
  logFile.print(',');
  printCsvEscFields(esc1);
  logFile.print(',');
  printCsvEscFields(esc2);
  logFile.println();

  rowsWritten++;
  rowsSinceFlush++;
  flushLogIfNeeded(false);
}

static void finishTelemetryCycle() {
  logCombinedRow(pendingMaster, pendingSlave);
  pendingMaster = EscSample{};
  pendingSlave = EscSample{};
  telState = TelState::Idle;
}

static void probeEsc(FlipskyUart &esc, const __FlashStringHelper *label) {
  esc.sendFwVersion();
  delay(100);
  esc.poll();
  Serial.print(label);
  Serial.print(F(" FW: "));
  if (esc.hasFwVersion()) {
    Serial.print(esc.fwMajor());
    Serial.print('.');
    Serial.println(esc.fwMinor());
  } else {
    Serial.println(F("no reply"));
  }
}

static void startTelemetryCycle() {
  pendingMaster = EscSample{};
  pendingSlave = EscSample{};
  masterEsc.clearTelemetryFlag();
  masterEsc.requestTelemetry(0);
  telWaitStartMs = millis();
  telState = TelState::WaitMaster;
}
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
void loop() {
  static unsigned long lastPpmFrameUs = 0;

  pollEscPorts();
  pollOneRcChannel();
  updateDrive();
  serviceTelemetryLogging();

  const unsigned long now = millis();
  const unsigned long nowUs = micros();

  if (ENABLE_DRIVE && DRIVE_MODE == DriveMode::PPM) {
    if (nowUs - lastPpmFrameUs >= (unsigned long)PPM_FRAME_US) {
      lastPpmFrameUs = nowUs;
      servicePpmOutputs();
    }
  } else {
    delay(2);
  }

  if (now - lastAliveMs >= ALIVE_INTERVAL_MS) {
    lastAliveMs = now;
    masterEsc.sendAlive();
    slaveEsc.sendAlive();
  }

  if (now - lastStatusMs >= STATUS_INTERVAL_MS) {
    lastStatusMs = now;
    Serial.print(F("rows="));
    Serial.print(rowsWritten);
    Serial.print(F(" thr="));
    Serial.print(logThrUs);
    Serial.print(F(" str="));
    Serial.print(logStrUs);
    Serial.print(F(" ppm M/S="));
    Serial.print(logMstPpmUs);
    Serial.print('/');
    Serial.print(logSlvPpmUs);
    Serial.print(F(" RX M="));
    Serial.print(masterEsc.rxBytes());
    Serial.print(F(" S="));
    Serial.println(slaveEsc.rxBytes());
    flushLogIfNeeded(true);
  }
}

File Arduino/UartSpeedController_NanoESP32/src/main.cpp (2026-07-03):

/*
 * UartSpeedController — Arduino Nano ESP32 (PlatformIO)
 *
 * FT85BD UART speed controller using Flipsky FT ESC protocol (AA ... DD).
 * Based on bring-up findings from Diagnostics/UartTelemetry_NanoESP32.
 *
 * USB Serial  -> debug monitor
 * Serial1     -> master COMM (D8 RX, D9 TX)  ID 101
 * Serial2     -> slave COMM  (D4 RX, D5 TX)  ID 102   [DUAL_UART_PORTS]
 *
 * Set ENABLE_UART_RPM_CONTROL to false for telemetry-only bring-up.
 *
 * Drive modes (see DRIVE_MODE):
 *   PPM — proven on this cart; ESC input = PPM, wires on D6/D10 -> COMM PPM
 *   UART_CMD32 — VX-remote style cmd 32 (experimental, no extra wires)
 *   UART_CURRENT — cmd 4 SET_CURRENT (experimental)
 */

#include <Arduino.h>
#include <driver/gpio.h>
#include "FlipskyUart.h"

// =====================
// FIRMWARE VERSION
// =====================
static const char FIRMWARE_VERSION[] = "1.2.4";

// =====================
// DRIVE OUTPUT MODE
// =====================
enum class DriveMode : uint8_t {
  PPM,            // ESC Input Signal Type = PPM (proven on meka cart)
  UART_CMD32,     // cmd 32 gear+current (VX-remote style guess)
  UART_CURRENT,   // cmd 4 signed current
};

// PPM is the known-good path on this cart. Try UART_CMD32 if you cannot rewire yet.
static const DriveMode DRIVE_MODE = DriveMode::PPM;

// =====================
// FEATURE FLAGS
// =====================
static const bool ENABLE_UART_RPM_CONTROL = true;

// =====================
// UART READ MODE
// =====================
enum class ReadMode : uint8_t {
  CAN_FORWARD_VIA_MASTER,
  DUAL_UART_PORTS,
};

static const ReadMode READ_MODE = ReadMode::DUAL_UART_PORTS;

// =====================
// PINS
// =====================
static const int THROTTLE_IN_PIN = D2;
static const int STEERING_IN_PIN = D3;
static const int MASTER_RX_PIN = D8;
static const int MASTER_TX_PIN = D9;
static const int SLAVE_RX_PIN = D4;
static const int SLAVE_TX_PIN = D5;

// PPM outputs (separate from UART TX pins). Wire to COMM **PPM** on each half.
static const int MASTER_PPM_PIN = D6;
static const int SLAVE_PPM_PIN = D10;

static const int PPM_MID_US = 1500;
static const int PPM_FORWARD_RANGE_US = 400;  // 50% of stick -> 1900 us
static const int PPM_REVERSE_RANGE_US = 144;  // 18% reverse cap -> 1356 us

// GPIO bit-bang PPM @ 50 Hz (LEDC is unreliable on Nano ESP32).
static const int PPM_FRAME_US = 20000;
static const int PPM_INTER_FRAME_GAP_US = 400;

class GpioPpmOut {
public:
  bool begin(int arduinoPin) {
    arduinoPin_ = arduinoPin;
    gpio_ = digitalPinToGPIONumber(arduinoPin);
    if (gpio_ < 0) {
      return false;
    }
    pinMode(arduinoPin, OUTPUT);
    gpio_set_level((gpio_num_t)gpio_, 0);
    pulseUs_ = PPM_MID_US;
    return true;
  }

  int gpio() const { return gpio_; }
  int arduinoPin() const { return arduinoPin_; }

  void writeMicroseconds(int pulseUs) {
    pulseUs_ = constrain(pulseUs, 500, 2500);
  }

  int pulseUs() const { return pulseUs_; }

  void emitPulse() const {
    if (gpio_ < 0) {
      return;
    }
    gpio_set_level((gpio_num_t)gpio_, 1);
    delayMicroseconds(pulseUs_);
    gpio_set_level((gpio_num_t)gpio_, 0);
  }

private:
  int arduinoPin_ = -1;
  int gpio_ = -1;
  int pulseUs_ = PPM_MID_US;
};

GpioPpmOut masterPpm;
GpioPpmOut slavePpm;

static void servicePpmOutputs() {
  const unsigned long frameStartUs = micros();
  masterPpm.emitPulse();
  delayMicroseconds(PPM_INTER_FRAME_GAP_US);
  slavePpm.emitPulse();
  const unsigned long elapsedUs = micros() - frameStartUs;
  if (elapsedUs < (unsigned long)PPM_FRAME_US) {
    delayMicroseconds((unsigned int)(PPM_FRAME_US - elapsedUs));
  }
}

// =====================
// ESC
// =====================
FlipskyUart masterEsc;
FlipskyUart slaveEsc;

static const unsigned long ESC_BAUD = 115200;
static const uint8_t MASTER_ESC_ID = 101;
static const uint8_t SLAVE_ESC_ID = 102;

static const float MAX_FORWARD_CURRENT_A = 40.0f;
static const float MAX_REVERSE_CURRENT_A = 15.0f;
static const float CURRENT_TO_MICROA = 1000000.0f;

// =====================
// RC TUNING — meka cart (stable, brake-at-neutral)
// =====================
// Forward stick = forward. Flip if your radio is reversed.
static const bool INVERT_THROTTLE = true;
static const bool INVERT_STEERING = false;
static const bool INVERT_MASTER = false;
static const bool INVERT_SLAVE = false;  // set motor direction in Flipsky ESC Tool instead

static const int RC_DEADBAND_US = 60;
static const float CMD_ZERO_THRESHOLD = 0.03f;

// Higher expo = softer low-speed response (less choppy than PPM breakaway kick).
static const float THROTTLE_EXPO = 0.60f;
static const float STEERING_EXPO = 0.50f;
static const float THROTTLE_RAMP_STEP = 0.015f;
static const float THROTTLE_BRAKE_RAMP_STEP = 0.06f;
static const float STEERING_RAMP_STEP = 0.020f;

// At speed: slow the inside wheel only (does not boost outside wheel — safer).
static const float SPEED_STEERING_GAIN = 0.30f;
static const float MAX_TURN_REDUCTION = 0.75f;

// Pivot in place is easy to flip the cart — off by default.
static const bool ENABLE_PIVOT_STEERING = false;
static const float PIVOT_THROTTLE_THRESHOLD = 0.06f;
static const float PIVOT_STEERING_GAIN = 0.18f;
static const float PIVOT_EXPO = 0.75f;
static const float PIVOT_RAMP_STEP = 0.010f;
static const float MASTER_PIVOT_GAIN_TRIM = 1.00f;
static const float SLAVE_PIVOT_GAIN_TRIM = 1.00f;
static const unsigned long SIGNAL_TIMEOUT_MS = 300;
static const int RC_PWM_MIN_US = 850;
static const int RC_PWM_MAX_US = 2150;

// =====================
// TIMING (from UartTelemetry_NanoESP32 bring-up)
// =====================
static const unsigned long TELEMETRY_INTERVAL_MS = 1000;
static const unsigned long RESPONSE_WAIT_MS = 25;
static const unsigned long ALIVE_INTERVAL_MS = 1000;

// =====================
// RC STATE (pulseIn polling — reliable on ESP32-S3)
// =====================
static int throttlePulse = 1500;
static int steeringPulse = 1500;
static unsigned long lastThrottleUpdateUs = 0;
static unsigned long lastSteeringUpdateUs = 0;
static uint32_t throttleValidCount = 0;
static uint32_t steeringValidCount = 0;
static bool throttleEver = false;
static bool steeringEver = false;
static uint8_t rcPollNext = 0;

static float throttleCurrent = 0;
static float steeringCurrent = 0;
static float pivotCurrent = 0;

static unsigned long lastTelemetryMs = 0;
static unsigned long lastAliveMs = 0;
static bool pollSlaveNext = false;
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

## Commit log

2026-06-11 Add GT-EV-Testbed firmware, ESC configs, and UART setup docs
    Establish the GT-EV-Testbed repository structure for the Georgia Tech
    ME 8803 EV cart platform with Arduino firmware, FT85BD XML configs,
    and project documentation.
    - Add SpeedReverseController (PPM differential drive + pivot steering)
    - Add UartSpeedController with VescUart helper for FT85BD telemetry
    and optional ERPM control over Serial1
    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
    [Edited_MasterMotorConfig529.xml, Edited_SlaveMotorConfig529.xml, LatestMasterMotorConfig529.xml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]
2026-07-01 Uploaded Tool1
    [3DprintBatDockLargeV1.0.stl, 3DprintBatDockLargeV1.1.stl, 3DprintBatDockLargeV1.2.stl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]
2026-07-01 Add FT85BD Flipsky UART telemetry diagnostic for Nano ESP32
    FT85BD COMM uses Flipsky UART (AA…DD, Modbus CRC16), not VESC packets.
    Add FlipskyUart.h and a read-only PlatformIO diagnostic that polls master
    (101) and slave (102) over separate COMM harnesses via Serial1 (D8/D9) and
    Serial2 (D4/D5). Verified on hardware: ~56.7 V pack, FW 1.6, independent
    IDs per half.
    - UartTelemetry_NanoESP32: dual-UART default, optional CAN-forward mode,
    boot harness check, README with bring-up findings and troubleshooting
    - FlipskyUart.h: telemetry, FW, alive, CAN-forward request helpers
    - VescUart.h: ESP32 explicit RX/TX pins, rxBytes/lastRaw debug helpers
    - Docs: Diagnostics order, Nano ESP32 wiring, r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
    [FlipskyUart.h, VescUart.h, main.cpp]
2026-07-03 Rewrite UartSpeedController for Flipsky FT protocol with PPM drive and dual UART telemetry
    Replaces the VescUart-based speed controller with a ground-up rewrite
    targeting the Flipsky FT85BD dual ESC using the native Flipsky UART
    protocol (AA … DD framing via FlipskyUart.h).
    Drive output:
    - Primary drive mode is now PPM via GPIO bit-bang on D6 (master) and
    D10 (slave), proven on the GT-EV meka cart with ESC control mode
    "Speed Reverse". ESP32Servo/LEDC was unreliable on the Nano ESP32
    so pulses are generated with direct gpio_set_level() + delayMicroseconds().
    - Experimental UART drive modes retained (cmd 4 SET_CURRENT, cmd 32
    gear+current) but PPM is the known-good path.
    Telemetry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
    [FlipskyUart.h, main.cpp]
2026-07-07 Add UART telemetry SD logger and document duty-cycle control progress
    Add UartTelemetryLogger_NanoESP32 — a read-only PlatformIO diagnostic that
    logs dual-UART FT85BD telemetry (voltage, RPM, duty, current, temps) to CSV
    on an Adafruit microSD SPI breakout (CS=D7, SPI on D11–D13).
    Extend FlipskyUart telemetry parsing with input current, duty cycle, and
    FET/motor temperature fields for richer logs.
    Update README with dated progress notes (2026-07-07) comparing current, speed,
    and duty-cycle control modes, plus TODOs including low-RPM steering tuning.
    Update Diagnostics and Wiring docs for dual UART + SD pin map.
    [FlipskyUart.h, main.cpp]
2026-07-07 Add engineering logbook with 107 build photos and narration transcript
    Create Docs/Logbook/ as a dated engineering record for the ME 8803 EV cart,
    transcribed from the 2026-07-07 narration video (video gitignored).
    - Add 107 session photos to Docs/Images/ (MMDDYY-N naming)
    - Add 16 dated logbook entries (2026-05-22 through 2026-07-07) with per-image
    captions, INDEX.md, and README
    - Include source transcript in Docs/Logbook/_source/ and Docs/Notes/
    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
2026-07-08 Added VescTool7.0
    Vesc Tool Tuner for VESC based ESC
2026-07-08 NanoESP32_datalogs and Exploration of stuttering and control modes
    duty cycle works well for low load applications however for hoverboard motors, we will likely need to utilize either current or speed reverse modes. dump of csv files from various tests and configs, last two are the speed reverse that seem like a stable start point for the ev and grid class. It may be recommended to try the official VESC esc.
    [tel_001.csv, tel_002.csv, tel_003.csv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]
